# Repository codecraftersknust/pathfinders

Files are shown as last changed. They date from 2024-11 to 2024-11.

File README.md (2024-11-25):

# Engineering materials

This repository contains engineering materials of a self-driven vehicle's model participating in the WRO Future Engineers competition in the season 2024.

## Content

* `t-photos` contains 2 photos of the team
* `v-photos` contains 6 photos of the vehicle
* `video` contains the video.md file with the link to a video where driving demonstration exists
* `schemes` contains one or several schematic diagrams in form of JPEG, PNG or PDF of the electromechanical components illustrating all the elements (electronic components and motors) used in the vehicle and how they connect to each other.
* `src` contains code of control software for all components which were programmed to participate in the competition
* `models` is for the files for models used by 3D printers to produce the vehicle elements.
* `docs` contains documents such as the BOM and general principles to help setup the project.

## 1. Mobility Management

### Chassis Design and Selection

* **Chassis:** LaTraxx Rally RC car chassis, selected for its robust design, stability, and adaptability to modifications.
* **Advantages:**
  * High durability and suitable for various terrains.
  * Pre-existing servo mount and ESC compatibility for smooth integration.
* **Modifications:** Mounted custom brackets for sensors and Raspberry Pi using 3D-printed parts.

### Motors

* **Drive Motor:** DC motor controlled by an ESC.
  * **Reason for Selection:** Provides high torque and speed for quick acceleration.
  * **Engineering Considerations:**
    * Speed: Capable of achieving consistent lap times on the track.
    * Torque: Sufficient to handle inclines and sharp turns.
    * Power: Optimized for the 6V NiMH battery.

* **Steering:** Chassis-integrated servo motor for precise control.

### Assembly Instructions

1. Mount the Raspberry Pi and Arduino Nano on the chassis using custom 3D-printed brackets.
2. Secure the ultrasonic sensors at the front and sides to maximize obstacle detection.
3. Connect the servo and ESC to the Arduino Nano via PWM.
4. Ensure all wiring is neatly routed to avoid interference with moving parts.
5. Use zip ties and adhesive pads to stabilize components.

---

## 2. Power and Sense Management

### Power Sources

* **Main Battery:** 11.1V LiPo, stepped down for:
  * **Raspberry Pi 3** (via a buck converter).
  * **Arduino Nano** (via USB of Pi).
* **Motor Battery:** 6V NiMH dedicated to the DC motor.
* **Reasoning:**
  * Separate power sources prevent voltage drops affecting the control systems.
  * Reduces noise interference from high-current components.

### Sensors

* **Ultrasonic Sensors:**
  * **Placement:** One at the front and one on each side for 360° obstacle detection.
  * **Usage:** Measure distances to walls and obstacles for navigation and avoidance.
* **Raspberry Pi Camera:**
  * **Purpose:** Line detection for track navigation.
  * **Implementation:** Mounted on a tilt bracket for adjustable angles.
  
### Wiring Diagram

[Can be found here](./schemes/README.md)

---

## 3. Obstacle Management

### Strategy

* **Navigation:**
  * Use the Raspberry Pi camera for detecting lines, red and green traffic symbols and corners.
  * Ultrasonic sensors ensure collision-free movement.

* **Control Flow:**
  * Raspberry Pi handles high-level decision-making.
  * Arduino Nano processes real-time sensor data and actuates motors accordingly.

## 4. Additional Resources

### Bill of Materials (BOM)

| **Component** | **Quantity** | **Description** | **Cost (USD)** | **URL** |
|---|---|---|---|---|
| Raspberry Pi 3 Model B+ | 1 | Main processor for navigation and control | $38.50 | [Buy from Cytron](https://www.cytron.io/p-raspberry-pi-3-model-b-plus) |
| Arduino Nano | 1 | Microcontroller for sensor and motor control | $15.99 | [Buy on Amazon](https://www.amazon.com/LAFVIN-Board-ATmega328P-Micro-Controller-Arduino/dp/B07G99NNXL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) |
| Pi Camera | 1 | Camera module for vision-based navigation | $45.99 | [Buy on Amazon](https://www.amazon.com/Arducam-Raspberry-Autofocus-Acrylic-15-22pin/dp/B0BX6N6V98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) |
| Ultrasonic Sensor (HC-SR04)| 1-3 | Distance measurement for wall following | $3.00 each | [Buy on Amazon](https://www.amazon.com/) |
| 11.1V 3S LiPo Battery | 1 | Power supply for the system | $98.99 |[Zeee](https://zeeebattery.com/collections/zeee-3s-lipo-battery/products/zeee-3s-lipo-battery-5200mah-11-1v-80c-ec5-2pack)|
| Step-Down Voltage Regulator| 1 | Converts 11.1V to required voltage levels for the Pi and motors | $6.71 | [Buy on Amazon](https://www.amazon.com/Seloky-Converter-Adjustable-Electronic-Stabilizer/dp/B0DBVYP91F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) |
| 1/18 LaTraxx Rally RC Chassis | 1 | Chassis and mechanical structure | $119.95 | [HobbyTown](https://www.hobbytown.com/traxxas-1-18-latrax-rally-rtr-4wd-electric-rally-car-green-blue-tra75054-5-grnx/p1460077) |
| 3D printed base plate | 1 | | | [STL file](../models/base-plate.stl)  |
| 3D printed base plate mount | 2 | | | [STL file](../models/base-plate-mount.stl) |
| 3D printed camera mount | 1 | | | [STL file](../models/camera-mount.stl) |
| Illuminated Halo Ring Switch | 2 | | $9.49 | [Amazon](https://www.amazon.com/API-ELE-warranty-Latching-Button-Metal1NO1NC/dp/B07932GYNH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) |
| Screw Pack (M2, M3) | 1 | | $8.19  |  [Amazon](https://www.amazon.com/gp/product/B01FXGHO2M/?th=1) |
| Micro SD Card (32GB) | 1 | Must be at least 32GB  | $49.99 | [Amazon](https://www.amazon.com/Samsung-MicroSDXC-Adapter-MB-ME64GA-AM/dp/B06XX29S9Q/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) |
| Jumper Wire Pack | 1 |  >15cm  | $6.98 | [Amazon](https://www.amazon.com/EDGELEC-Breadboard-Optional-Assorted-Multicolored/dp/B07GD2BWPY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) |

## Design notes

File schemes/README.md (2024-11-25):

# Electromechanical diagrams

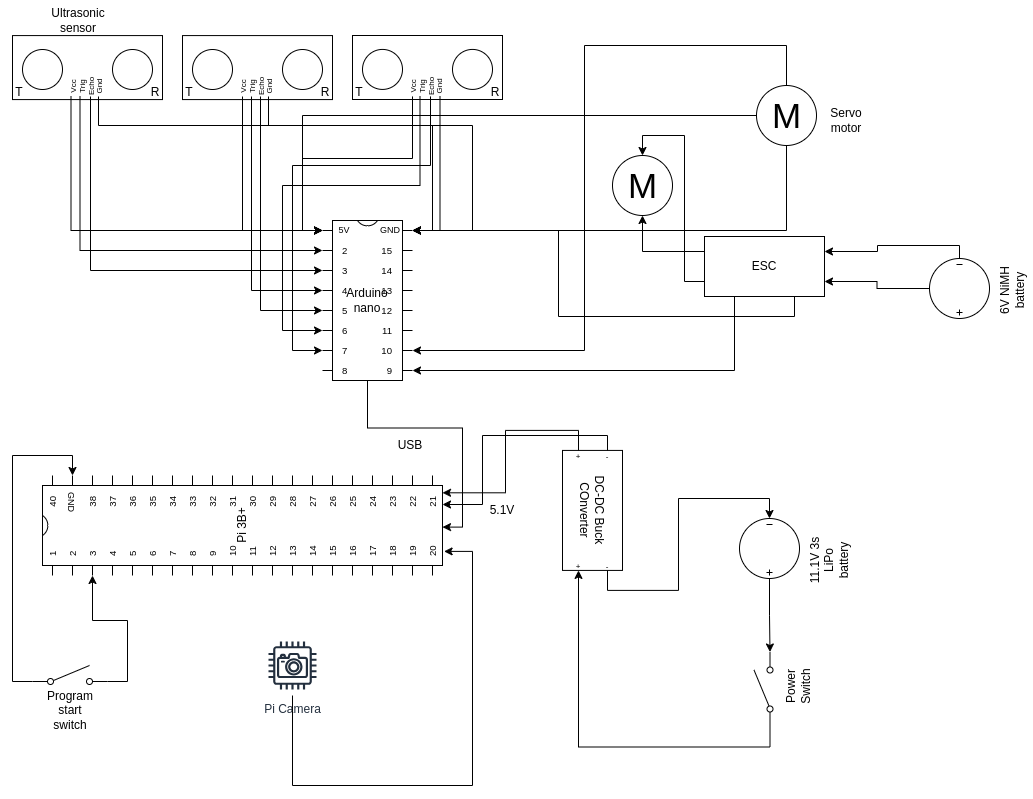
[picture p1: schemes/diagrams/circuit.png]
Schematic Diagram


> **Note:** All schematic diagrams can be found in the `/diagrams` folder in PNG format.

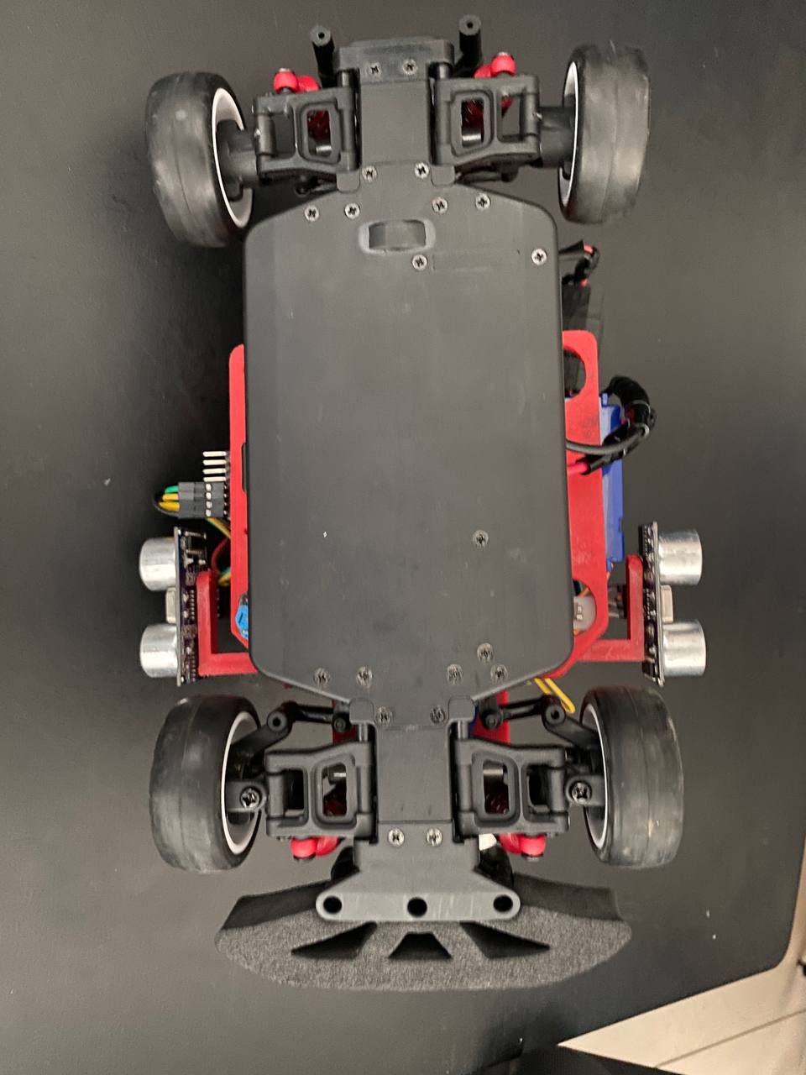
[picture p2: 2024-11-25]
v-photos/bottom.jpg

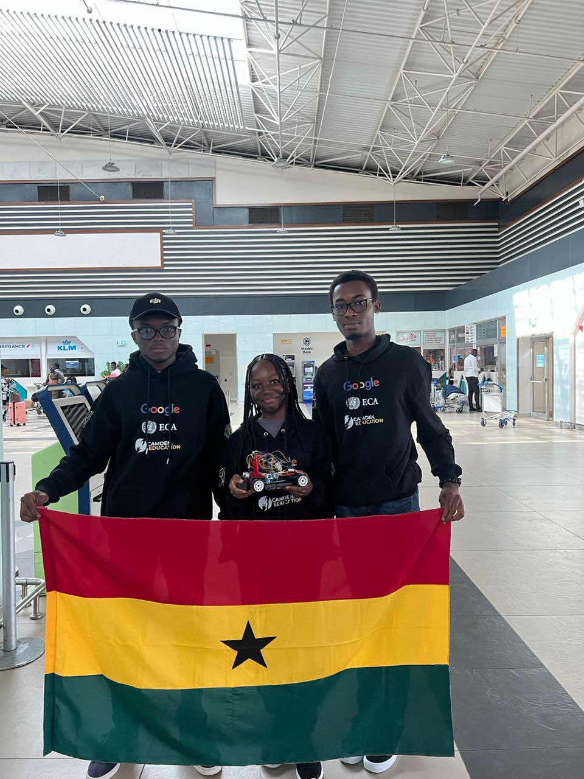
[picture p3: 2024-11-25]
t-photos/t-photo-1.jpg

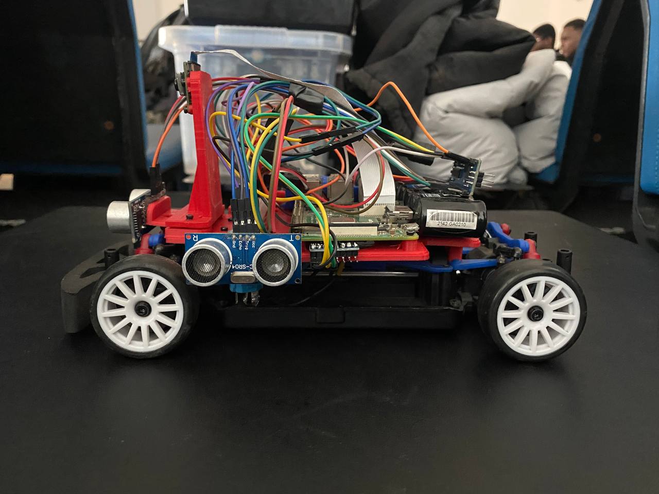
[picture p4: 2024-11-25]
v-photos/left.jpg

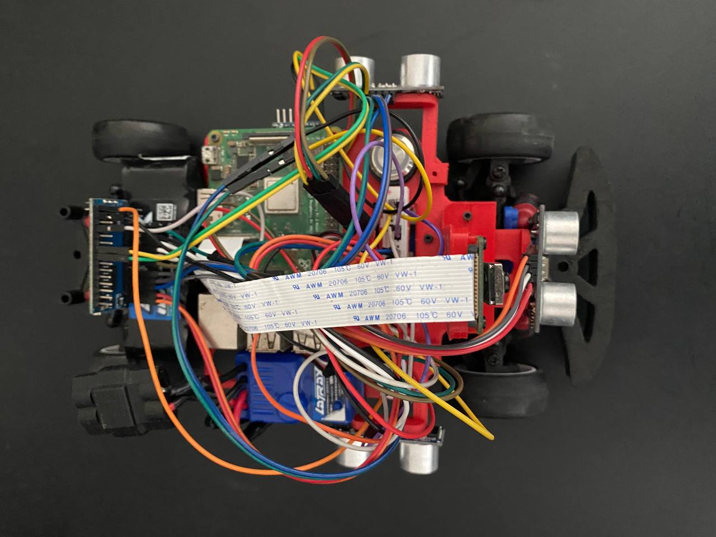
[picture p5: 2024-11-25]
v-photos/top.jpg

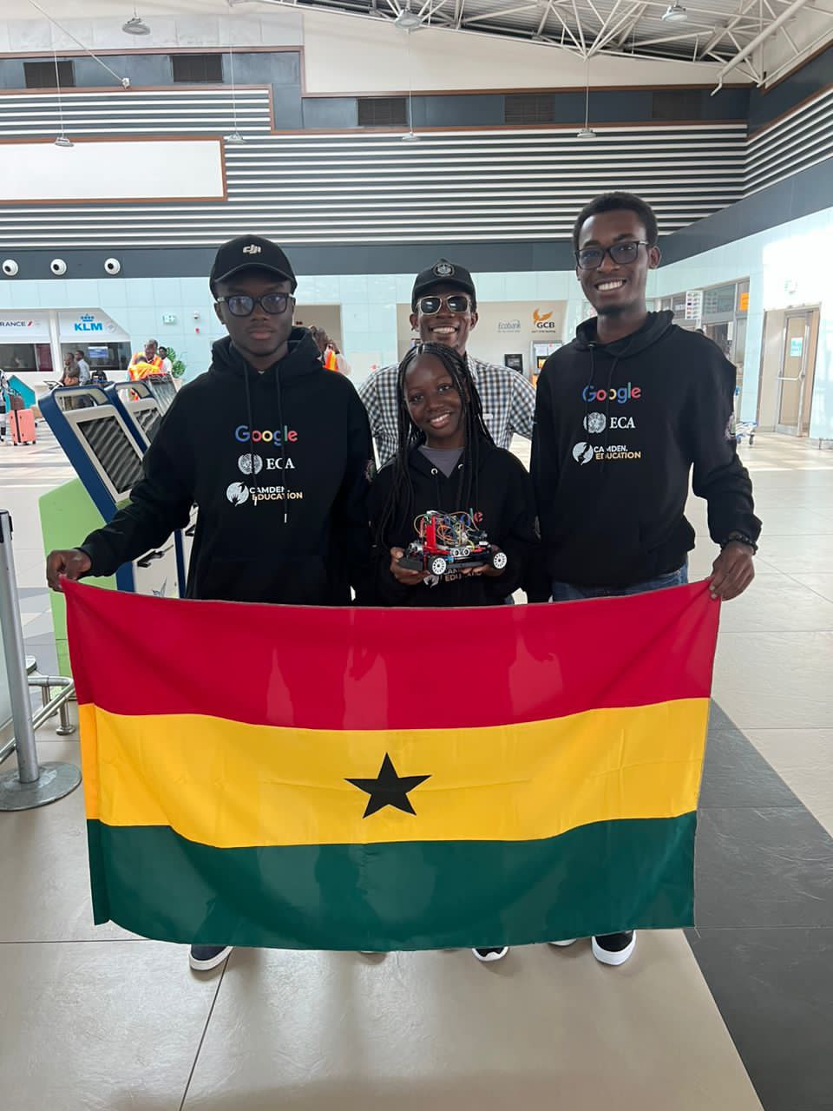
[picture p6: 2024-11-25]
t-photos/t-photo-2.jpg

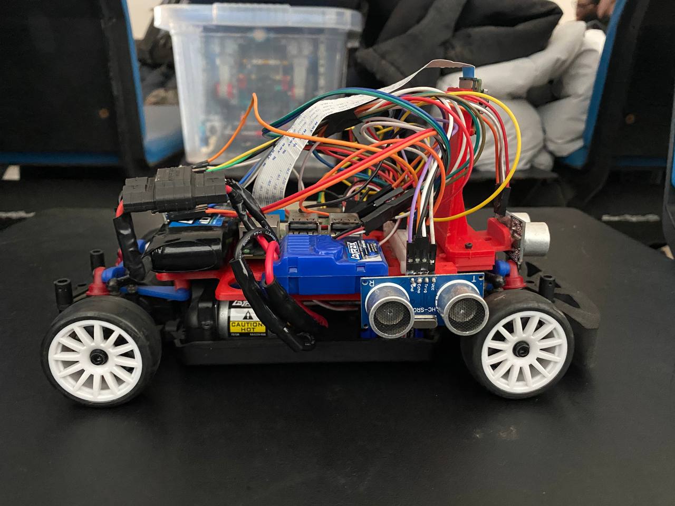
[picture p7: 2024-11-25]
v-photos/right.jpg

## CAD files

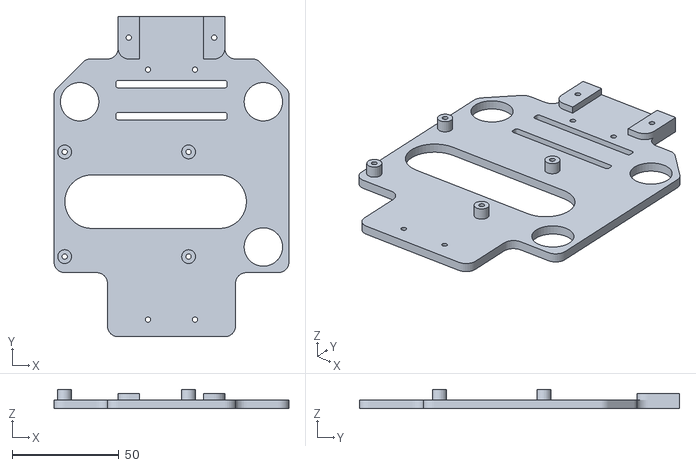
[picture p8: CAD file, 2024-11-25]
models/base-plate.stl
110.0 x 150.0 x 9.00

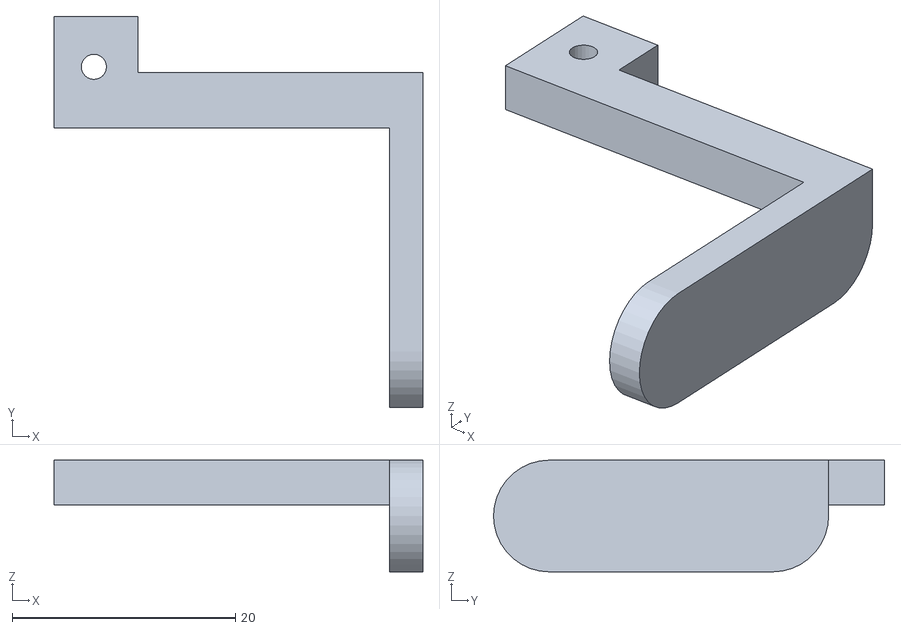
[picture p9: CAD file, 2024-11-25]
models/right-ultrasonic-mount.stl
33.0 x 35.0 x 10.0

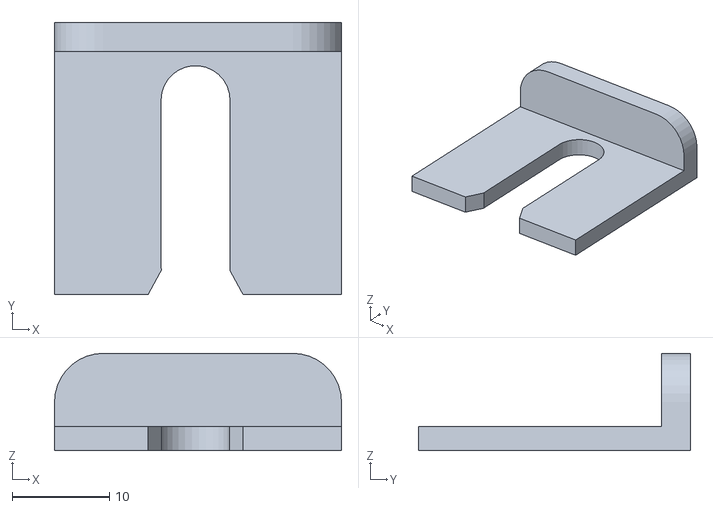
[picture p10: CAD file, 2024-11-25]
models/front-ultrasonic-mount.stl
29.5 x 28.0 x 10.0

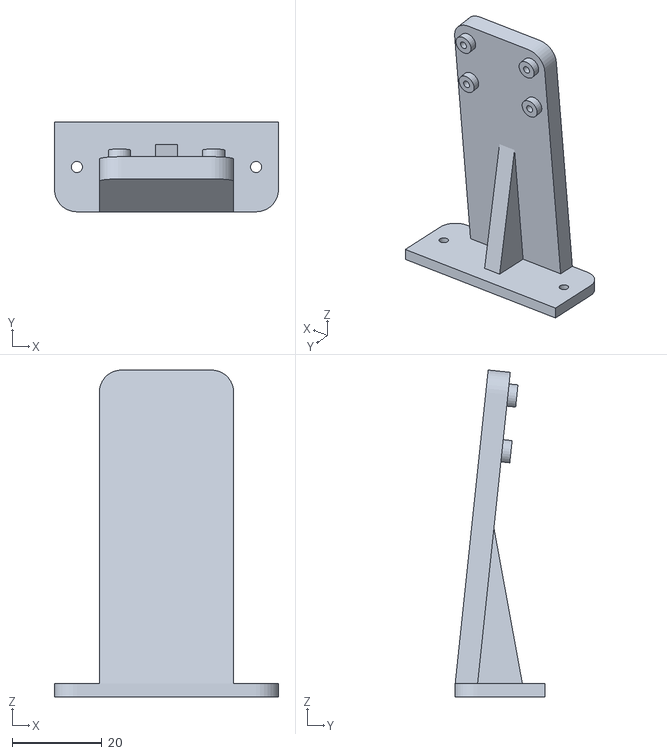
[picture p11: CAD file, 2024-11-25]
models/camera-mount.stl
50.0 x 20.0 x 73.0

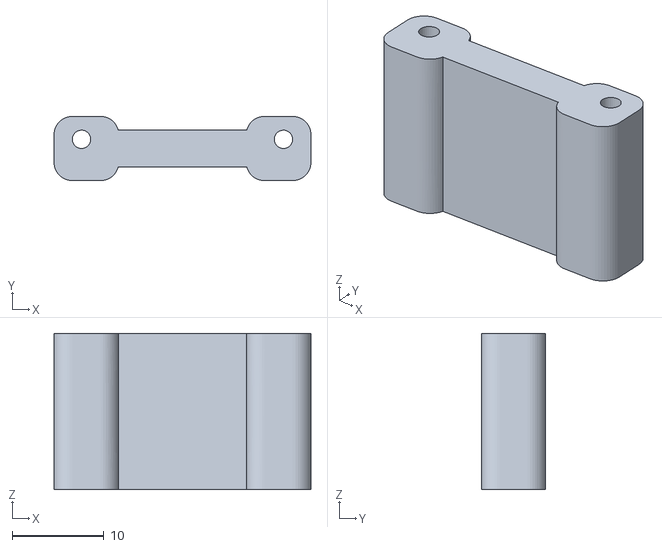
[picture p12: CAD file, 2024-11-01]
models/base-plate-mount.stl
28.0 x 7.00 x 17.0

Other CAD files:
models/left-ultrasonic-mount.stl

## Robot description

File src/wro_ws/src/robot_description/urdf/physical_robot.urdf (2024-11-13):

<?xml version="1.0" ?>
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
<robot name="my_robot">
  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
  <link name="base_link">
    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
    <inertial>
      <origin rpy="0 0 0" xyz="0 0 0"/>
      <mass value="1"/>
      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
    </inertial>
  </link>
  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
  <link name="virtual_rear_wheel">
    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
  </link>
  <joint name="virtual_rear_wheel_joint" type="continuous">
    <parent link="base_link"/>
    <child link="virtual_rear_wheel"/>
    <origin rpy="0 0 1.5707963267948966" xyz="-0.08 0 -0.03"/>
    <axis rpy="0 0 0" xyz="1 0 0"/>
    <limit effort="100.0" velocity="100.0"/>
    <dynamics damping="0.2"/>
  </joint>
  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
  <link name="rear_right_wheel">
    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
    <inertial>
      <origin rpy="1.5707963267948966 0 1.5707963267948966" xyz="0 0 0"/>
      <mass value="0.1"/>
      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
    </inertial>
  </link>
  <joint name="rear_right_wheel_joint" type="continuous">
    <parent link="base_link"/>
    <child link="rear_right_wheel"/>
    <origin rpy="0 0 1.5707963267948966" xyz="-0.08 0.085 -0.03"/>
    <axis rpy="0 0 0" xyz="1 0 0"/>
    <limit effort="100.0" velocity="100.0"/>
    <dynamics damping="0.2"/>
    <mimic joint="virtual_rear_wheel_joint" multiplier="1.0" offset="0.0"/>
  </joint>
  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
  <link name="rear_left_wheel">
    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
    <inertial>
      <origin rpy="1.5707963267948966 0 1.5707963267948966" xyz="0 0 0"/>
      <mass value="0.1"/>
      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
    </inertial>
  </link>
  <joint name="rear_left_wheel_joint" type="continuous">
    <parent link="base_link"/>
    <child link="rear_left_wheel"/>
    <origin rpy="0 0 1.5707963267948966" xyz="-0.08 -0.085 -0.03"/>
    <axis rpy="0 0 0" xyz="1 0 0"/>
    <limit effort="100.0" velocity="100.0"/>
    <dynamics damping="0.2"/>
    <mimic joint="virtual_rear_wheel_joint" multiplier="1.0" offset="0.0"/>
  </joint>
  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
  <link name="virtual_front_wheel">
    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
  </link>
  <joint name="virtual_front_wheel_joint" type="revolute">
    <parent link="base_link"/>
    <child link="virtual_front_wheel"/>
    <origin rpy="0 0 1.5707963267948966" xyz="0.08 0 -0.03"/>
    <axis xyz="0 0 1"/>
    <limit effort="100.0" lower="-0.7853" upper="0.7853" velocity="100.0"/>
    <dynamics damping="0.2"/>
  </joint>
  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
  <link name="front_right_wheel">
    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
    <inertial>
      <origin rpy="1.5707963267948966 0 1.5707963267948966" xyz="0 0 0"/>
      <mass value="0.1"/>
      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
    </inertial>
  </link>
  <joint name="front_right_wheel_joint" type="revolute">
    <parent link="base_link"/>
    <child link="front_right_wheel"/>
    <origin rpy="0 0 1.5707963267948966" xyz="0.08 0.085 -0.03"/>
    <axis xyz="0 0 1"/>
    <limit effort="100.0" lower="-0.7853" upper="0.7853" velocity="100.0"/>
    <dynamics damping="0.2"/>
    <mimic joint="virtual_front_wheel_joint" multiplier="1.0" offset="0.0"/>
  </joint>
  <link name="front_left_wheel">
    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
    <inertial>
      <origin rpy="1.5707963267948966 0 1.5707963267948966" xyz="0 0 0"/>
      <mass value="0.1"/>
      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
    </inertial>
  </link>
  <joint name="front_left_wheel_joint" type="revolute">
    <parent link="base_link"/>
    <child link="front_left_wheel"/>
    <origin rpy="0 0 1.5707963267948966" xyz="0.08 -0.085 -0.03"/>
    <axis xyz="0 0 1"/>
    <limit effort="100.0" lower="-0.7853" upper="0.7853" velocity="100.0"/>
    <dynamics damping="0.2"/>
    <mimic joint="virtual_front_wheel_joint" multiplier="1.0" offset="0.0"/>
  </joint>
  <ros2_control name="RobotControl" type="system">
    <hardware>
      <plugin>bicdrive_arduino/CarlikeBotSystemHardware</plugin>
      <param name="front_wheel_name">virtual_front_wheel_joint</param>
      <param name="rear_wheel_name">virtual_rear_wheel_joint</param>
      <param name="loop_rate">30</param>
      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
      <param name="device">/dev/serial/by-path/pci-0000:00:14.0-usb-0:4:1.0-port0</param>
      <param name="baud_rate">9600</param>
      <param name="timeout_ms">1000</param>
    </hardware>
    <joint name="virtual_front_wheel_joint">
      <command_interface name="position"/>
      <state_interface name="position"/>
    </joint>
    <joint name="virtual_rear_wheel_joint">
      <command_interface name="velocity"/>
      <state_interface name="velocity"/>
    </joint>
  </ros2_control>
  <joint name="laser_joint" type="fixed">
    <parent link="base_link"/>
    <child link="laser_frame"/>
    <origin rpy="0 0 0" xyz="0 0 0.038"/>
  </joint>
  <link name="laser_frame">
    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
    <inertial>
      <origin rpy="0 0 0" xyz="0 0 0"/>
      <mass value="1.0"/>
      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
    </inertial>
  </link>
  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
  <joint name="camera_joint" type="fixed">
    <parent link="base_link"/>
    <child link="camera_link"/>
    <origin rpy="0 0 0" xyz="0.128 0 0"/>
  </joint>
  <link name="camera_link">
    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
  </link>
  <joint name="camera_optical_joint" type="fixed">
    <parent link="camera_link"/>
    <child link="camera_link_optical"/>
    <origin rpy="-1.5707963267948966 0 -1.5707963267948966" xyz="0 0 0"/>
  </joint>
  <link name="camera_link_optical"/>
  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
</robot>

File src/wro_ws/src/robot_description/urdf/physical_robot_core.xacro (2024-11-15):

<?xml version="1.0"?>
<robot xmlns:xacro="http://www.ros.org/wiki/xacro">

  <xacro:include filename="colors.xacro" />
  <xacro:include filename="inertial_macros.xacro" />

  <xacro:property name="PI" value="3.1415926535897931"/>
  <xacro:property name="base_mass" value="1" /> 
  <xacro:property name="base_width" value="0.17" />
  <xacro:property name="base_length" value="0.25" />
  <xacro:property name="base_height" value="0.06" />
  <xacro:property name="wheelbase" value="0.16" />
  <xacro:property name="wheel_mass" value="0.1" />
  <xacro:property name="wheel_len" value="0.018" />
  <xacro:property name="wheel_radius" value="0.0215" />
  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

  
  <link name="base_link">
    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

    <inertial>
      <origin xyz="0 0 0" rpy="0 0 0"/>
      <mass value="${base_mass}"/>
        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
      </inertial>
    </link>

    <joint name="base_footprint_joint" type="fixed">
        <parent link="base_link"/>
        <child link="base_footprint"/>
        <origin xyz="0 0 0" rpy="0 0 0"/>
    </joint>

              
    <link name="base_footprint">
    </link>

    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

    <link name="virtual_rear_wheel">
      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
    </link>

    <joint name="virtual_rear_wheel_joint" type="continuous">
      <parent link="base_link"/>
      <child link="virtual_rear_wheel"/>
      <origin xyz="-${wheelbase/2} 0 -${base_height/2}" rpy="0 0 ${PI/2}"/>
      <axis xyz="1 0 0" rpy="0 0 0"/>
      <limit effort="100.0" velocity="100.0"/>
      <dynamics damping="0.2"/>
    </joint>

    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

    <link name="rear_right_wheel">
      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

      <inertial>
        <origin xyz="0 0 0" rpy="${PI/2} 0 ${PI/2}"/>
        <mass value="${wheel_mass}"/>
        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
      </inertial>

    </link>

    <joint name="rear_right_wheel_joint" type="continuous">
      <parent link="base_link"/>
      <child link="rear_right_wheel"/>
      <origin xyz="-${wheelbase/2} ${base_width/2} -${base_height/2}" rpy="0 0 ${PI/2}"/>
      <axis xyz="1 0 0" rpy="0 0 0"/>
      <limit effort="100.0" velocity="100.0"/>
      <dynamics damping="0.2"/>
      <mimic joint="virtual_rear_wheel_joint" multiplier="1.0" offset="0.0"/>
    </joint>

    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
    <link name="rear_left_wheel">
        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

        <inertial>
          <origin xyz="0 0 0" rpy="${PI/2} 0 ${PI/2}"/>
          <mass value="${wheel_mass}"/>
          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
        </inertial>

    </link>

    <joint name="rear_left_wheel_joint" type="continuous">
      <parent link="base_link" />
      <child link="rear_left_wheel" />
      <origin xyz="-${wheelbase/2} -${base_width/2} -${base_height/2}" rpy="0 0 ${PI/2}"/>
      <axis xyz="1 0 0" rpy="0 0 0" />
      <limit effort="100.0" velocity="100.0"/>
      <dynamics damping="0.2"/>
      <mimic joint="virtual_rear_wheel_joint" multiplier="1.0" offset="0.0"/>
    </joint>

    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

    <link name="virtual_front_wheel">
      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
    </link>

    <joint name="virtual_front_wheel_joint" type="revolute">
      <parent link="base_link"/>
      <child link="virtual_front_wheel"/>
      <origin xyz="${wheelbase/2} 0 -${base_height/2}" rpy="0 0 ${PI/2}"/>
      <axis xyz="0 0 1"/>
      <limit lower="-0.7853" upper="0.7853" effort="100.0" velocity="100.0"/>
      <dynamics damping="0.2"/>
    </joint>

    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


    <link name="front_right_wheel">

      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

      <inertial>
        <origin xyz="0 0 0" rpy="${PI/2} 0 ${PI/2}"/>
        <mass value="${wheel_mass}"/>
        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
      </inertial>
    </link>

    <joint name="front_right_wheel_joint" type="revolute">
      <parent link="base_link" />
      <child link="front_right_wheel" />
      <origin xyz="${wheelbase/2} ${base_width/2} -${base_height/2}" rpy="0 0 ${PI/2}"/>
      <axis xyz="0 0 1"/>
      <limit lower="-0.7853" upper="0.7853" effort="100.0" velocity="100.0"/>
      <dynamics damping="0.2"/>
      <mimic joint="virtual_front_wheel_joint" multiplier="1.0" offset="0.0"/>
    </joint>

    <link name="front_left_wheel">
      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

      <inertial>
        <origin xyz="0 0 0" rpy="${PI/2} 0 ${PI/2}"/>
        <mass value="${wheel_mass}"/>
        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
      </inertial>
    </link>

    <joint name="front_left_wheel_joint" type="revolute">
      <parent link="base_link" />
      <child link="front_left_wheel" />
      <origin xyz="${wheelbase/2} -${base_width/2} -${base_height/2}" rpy="0 0 ${PI/2}"/>
      <axis xyz="0 0 1"/>
      <limit lower="-0.7853" upper="0.7853" effort="100.0" velocity="100.0"/>
      <dynamics damping="0.2"/>
      <mimic joint="virtual_front_wheel_joint" multiplier="1.0" offset="0.0"/>
    </joint>


</robot>

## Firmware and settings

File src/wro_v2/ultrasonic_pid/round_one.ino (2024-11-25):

#include <Servo.h>

// Pin definitions
const int TRIG_LEFT = 10;
const int ECHO_LEFT = 9;
const int TRIG_RIGHT = 3;
const int ECHO_RIGHT = 2;
const int ESC_PIN = 5;
const int SERVO_PIN = 6;

// ESC calibration values
const int NEUTRAL_PULSE = 1500;
const int FULL_THROTTLE = 2000;
const int FULL_REVERSE = 1000;

const float Kp = 1.5;
const float Ki = 0.0;
const float Kd = 0.0;
const float FORWARD_SPEED = 1000;

float error = 0;
float previous_error = 0;
float integral = 0;
float derivative = 0;
float output = 0;

// Servo angles
const int CENTER_ANGLE = 90;
const int MAX_STEERING_ANGLE = 30;  // Maximum deviation from center

// Global variables
Servo esc;
Servo steering;
float lastError = 0;
unsigned long lastTime = 0;

void setup() {
  // Initialize serial communication
  Serial.begin(9600);
  
  // Initialize ultrasonic sensor pins
  pinMode(TRIG_LEFT, OUTPUT);
  pinMode(ECHO_LEFT, INPUT);
  pinMode(TRIG_RIGHT, OUTPUT);
  pinMode(ECHO_RIGHT, INPUT);
  
  // Attach and initialize servo and ESC
  esc.attach(ESC_PIN);
  steering.attach(SERVO_PIN);
  
  // Center the steering
  steering.write(CENTER_ANGLE);
  delay(1000);
}

void loop() {
  // Get current distance from wall
  float distanceLeft = getDistance(TRIG_LEFT, ECHO_LEFT);
  float distanceRight = getDistance(TRIG_RIGHT, ECHO_RIGHT);
  
  // Calculate error
  error = distanceLeft - distanceRight;
  
  // Calculate time difference
  unsigned long currentTime = millis();
  float deltaTime = (currentTime - lastTime) / 1000.0;  // Convert to seconds
  
  // Calculate derivative of error
  derivative = (error - lastError) / deltaTime;
  
  // Calculate PD control output
  output = (Kp * error) + (Ki * integral) + (Kd * derivative);
  
  // Limit control output to maximum steering angle
  output = constrain(output, -MAX_STEERING_ANGLE, MAX_STEERING_ANGLE);
  
  // Convert control output to steering angle
  int steeringAngle = CENTER_ANGLE + output;
  
  // Apply steering control
  steering.write(steeringAngle);
  
  // Set forward motion
  esc.writeMicroseconds(FORWARD_SPEED);
  
  // Update previous values
  lastError = error;
  lastTime = currentTime;
  
  // Debug output
  Serial.print("Left Distance: ");
  Serial.print(distanceLeft);
  Serial.print(" cm, Right Distance: ");
  Serial.print(distanceRight);
  Serial.print(" cm, Error: ");
  Serial.print(error);
  Serial.print(", Servo Angle: ");
  Serial.println(steeringAngle);
  
  delay(50);
}

float getDistance(int trigPin, int echoPin) {
  digitalWrite(trigPin, LOW);
  delayMicroseconds(2);
  digitalWrite(trigPin, HIGH);
  delayMicroseconds(10);
  digitalWrite(trigPin, LOW);
  
  long duration = pulseIn(echoPin, HIGH);
  return duration * 0.034 / 2;  // Convert to cm
}

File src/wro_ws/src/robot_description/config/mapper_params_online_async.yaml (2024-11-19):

slam_toolbox:
  ros__parameters:

    # Plugin params
    solver_plugin: solver_plugins::CeresSolver
    ceres_linear_solver: SPARSE_NORMAL_CHOLESKY
    ceres_preconditioner: SCHUR_JACOBI
    ceres_trust_strategy: LEVENBERG_MARQUARDT
    ceres_dogleg_type: TRADITIONAL_DOGLEG
    ceres_loss_function: None

    # ROS Parameters
    odom_frame: odom
    map_frame: map
    base_frame: base_link
    scan_topic: /scan
    use_map_saver: true
    mode: mapping

    # if you'd like to immediately start continuing a map at a given pose
    # or at the dock, but they are mutually exclusive, if pose is given
    # will use pose
    # map_file_name: /home/sojourner/Documents/pathfinders/src/wro_ws/map/default_map
    # map_start_pose: [0.0, 0.0, 0.0]
    # map_start_at_dock: true

    debug_logging: false
    throttle_scans: 1
    transform_publish_period: 0.02 #if 0 never publishes odometry
    map_update_interval: 5.0
    resolution: 0.05
    max_laser_range: 20.0 #for rastering images
    minimum_time_interval: 0.5
    transform_timeout: 0.2
    tf_buffer_duration: 30.
    stack_size_to_use: 40000000 #// program needs a larger stack size to serialize large maps
    enable_interactive_mode: true

    # General Parameters
    use_scan_matching: true
    use_scan_barycenter: true
    minimum_travel_distance: 0.5
    minimum_travel_heading: 0.5
    scan_buffer_size: 10
    scan_buffer_maximum_scan_distance: 10.0
    link_match_minimum_response_fine: 0.1  
    link_scan_maximum_distance: 1.5
    loop_search_maximum_distance: 3.0
    do_loop_closing: true 
    loop_match_minimum_chain_size: 10           
    loop_match_maximum_variance_coarse: 3.0  
    loop_match_minimum_response_coarse: 0.35    
    loop_match_minimum_response_fine: 0.45

    # Correlation Parameters - Correlation Parameters
    correlation_search_space_dimension: 0.5
    correlation_search_space_resolution: 0.01
    correlation_search_space_smear_deviation: 0.1 

    # Correlation Parameters - Loop Closure Parameters
    loop_search_space_dimension: 8.0
    loop_search_space_resolution: 0.05
    loop_search_space_smear_deviation: 0.03

    # Scan Matcher Parameters
    distance_variance_penalty: 0.5      
    angle_variance_penalty: 1.0    

    fine_search_angle_offset: 0.00349     
    coarse_search_angle_offset: 0.349   
    coarse_angle_resolution: 0.0349        
    minimum_angle_penalty: 0.9
    minimum_distance_penalty: 0.5
    use_response_expansion: true

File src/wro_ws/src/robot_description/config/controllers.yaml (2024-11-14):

controller_manager:
  ros__parameters:
    update_rate: 1000
    use_sim_time: false

    ack_cont:
      type: ackermann_steering_controller/AckermannSteeringController

    bic_cont:
      type: bicycle_steering_controller/BicycleSteeringController

    joint_broad:
      type: joint_state_broadcaster/JointStateBroadcaster

ack_cont:
  ros__parameters:
    reference_timeout: 2.0
    front_steering: true
    open_loop: false
    velocity_rolling_window_size: 10
    position_feedback: false
    rear_wheels_names: [left_rear_wheel_joint, right_rear_wheel_joint]
    front_wheels_names: [left_front_steering_joint, right_front_steering_joint]

    front_wheel_track: 0.172
    rear_wheel_track: 0.172
    wheelbase: 0.21
    front_wheels_radius: 0.0215
    rear_wheels_radius: 0.0215

bic_cont:
  ros__parameters:
    reference_timeout: 2.0
    front_steering: true
    open_loop: false
    velocity_rolling_window_size: 10      
    position_feedback: false
    front_wheels_names: [virtual_front_wheel_joint]
    rear_wheels_names: [virtual_rear_wheel_joint]
    base_frame_id: base_link
    odom_frame_id: odom
    enable_odom_tf: false
    wheelbase: 0.21
    front_wheel_radius: 0.0215
    rear_wheel_radius: 0.0215
    twist_covariance_diagonal: [0.0, 7.0, 14.0, 21.0, 28.0, 35.0]
    pose_covariance_diagonal: [0.0, 7.0, 14.0, 21.0, 28.0, 35.0]
    use_stamped_vel: false

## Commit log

2024-04-01 Add environment for simulation in gazebo
    [wro_world.sdf]
2024-04-28 Complete ignition world for simulation
    [wro_world.sdf]
2024-07-09 camera stand initial build
    [cam.stl]
2024-07-10 main board initial build
    [mainBoard.stl]
2024-08-29 New base design for jetson orin nano
    [base.stl, cam.stl, camera-stand.stl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]
2024-09-03 Add complete robot and world for simulation
    [ackermann.urdf, ackermann.urdf.xacro, colors.xacro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]
2024-09-03 Remove extra workspace
    [ackermann.urdf, example_robot.urdf.xacro, gazebo_wro_world.sdf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]
2024-09-04 Add Laser scan to simulatiom
    [lidar.xacro, robot.urdf.xacro, robot_core.xacro]
2024-09-06 Add cameras to simulation
    [camera.xacro, depth_camera.xacro, lidar.xacro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]
2024-09-20 add base stand model
    [stand.stl]
2024-10-14 Add accurate robot description
    [ackermann.urdf.xacro, camera.xacro, colors.xacro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]
2024-10-14 Add lidar
    [lidar.xacro, robot.urdf.xacro]
2024-10-15 Add lidar packages
2024-10-15 Select right frame for lidar
2024-10-15 final design
    [base-base.stl, base-plate-mount.stl, base.stl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]
2024-11-01 Set up ros2 control and write plugin for ackerman steering
    [colors.xacro, controllers.yaml, final_bot.urdf.xacro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]
2024-11-08 Update components and wiring diagram
2024-11-08 Final base model
    [base-base.stl]
2024-11-08 Management docs and BOM
2024-11-08 Change configurations
    [ros2_control_bic.xacro]
2024-11-08 Edit hardware interface
    [ros2_control_bic.xacro]
2024-11-08 ros2 bicycle control plugin
    [ros2_control_bic.xacro]
2024-11-08 Use unstamped velocity
    [controllers.yaml]
2024-11-09 Reset steering initial position and convert radians to degrees
2024-11-09 Fix steering range
2024-11-13 Fix plugin to publish state of traction wheel position
    [controllers.yaml, depth_camera.xacro, physical_robot.urdf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]
2024-11-14 Set up laser odometry
    [controllers.yaml]
2024-11-14 Set up sensors for SLAM
    [ros2_control_bic.xacro]
2024-11-14 Add laser odometry files
2024-11-15 Add default maps
    [physical_robot_core.xacro]
2024-11-20 Set up sensor fusion between lidar and imu for odometry
    [depth_camera.xacro, ros2_control_bic.xacro]
2024-11-20 Disable camera and sensor fusion
2024-11-23 change in equipment
    [base-base.stl, base-plate.stl, camera-mount.stl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]
2024-11-25 Add ultrasonic pid
